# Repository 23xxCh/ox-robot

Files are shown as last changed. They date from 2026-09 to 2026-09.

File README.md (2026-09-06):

# 牛来 / ox-robot

有人靠近时它先停着等人喊；喊「牛来」先播电影「妈妈」片段，再礼貌听、想、说。人离开后，它才过自己的生活。

一块小智 S3 扩展板 V1.7 负责听、说、屏、灯、键、超声和四路舵机信号。笔记本上的 `brain/` 负责人格、记忆和动作编排。不把完整 ESP-Claw 固件并进小智。

- 仓库：https://github.com/23xxCh/ox-robot
- 最终汇报：[PDF](./outputs/submission-2026-09-06/牛来-最终汇报.pdf) · [Word](./outputs/submission-2026-09-06/牛来-最终汇报.docx)
- Checkpoint 1：[牛来机器人-进展说明-2026-09-05.md](./牛来机器人-进展说明-2026-09-05.md)
- Checkpoint 2：[牛来机器人-Checkpoint2-进展说明-2026-09-06.md](./牛来机器人-Checkpoint2-进展说明-2026-09-06.md)
- Submission：[牛来机器人-Submission-2026-09-06.md](./牛来机器人-Submission-2026-09-06.md)

## 架构

当前实现：**一块小智 ESP32-S3 板 + 笔记本本地大脑 + 按配置启用的云语音/模型服务**。

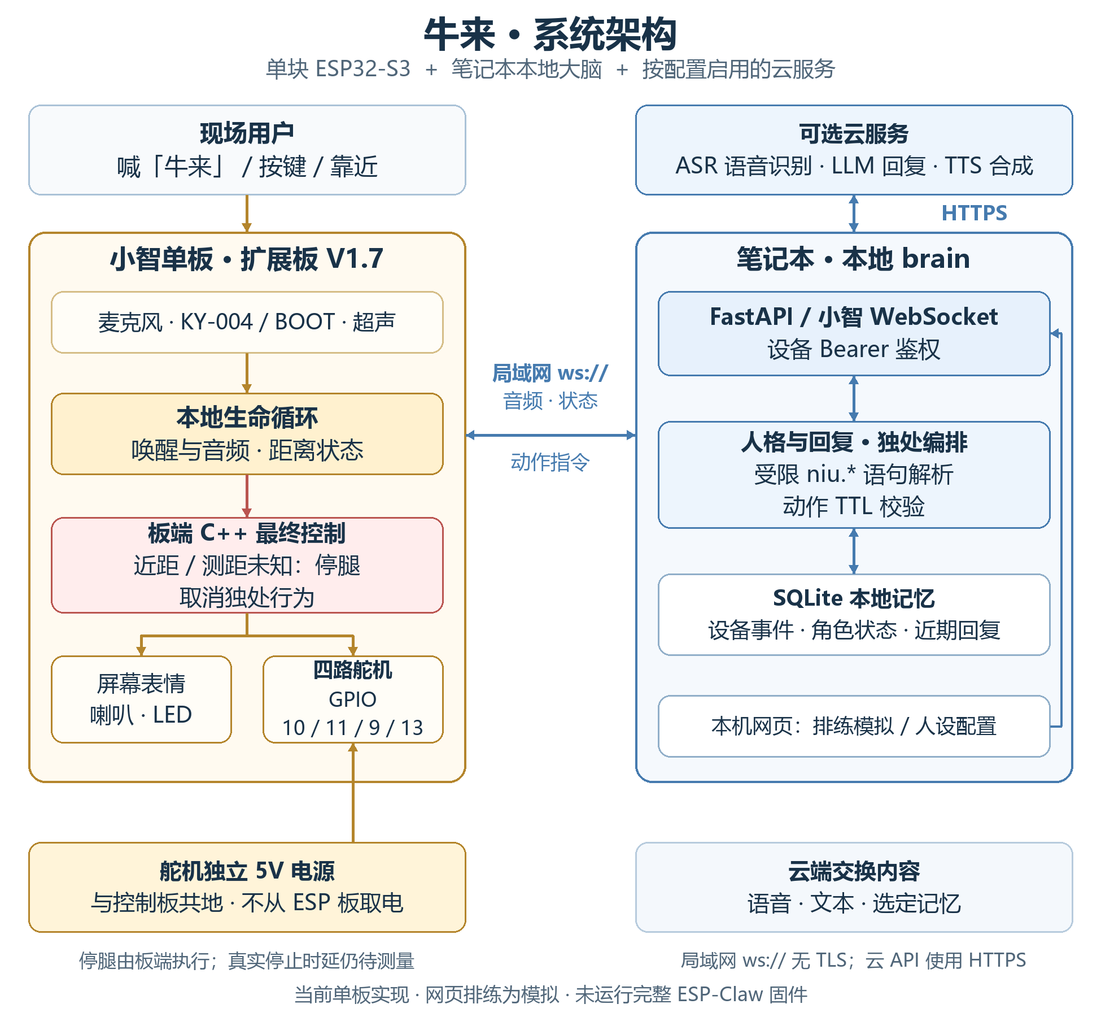
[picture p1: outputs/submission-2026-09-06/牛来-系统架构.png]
牛来当前系统架构


<details>
<summary>查看可编辑的 Mermaid 架构图</summary>

```mermaid
flowchart TB
    User["现场用户：喊牛来 / 按键 / 靠近"]

    subgraph Robot["牛来实体 · 小智 S3 扩展板 V1.7"]
        Input["麦克风 · KY-004 / BOOT · 超声测距"]
        Board["小智固件 + 牛来板型 overlay<br/>唤醒与音频 · 距离状态 · 本地生命循环"]
        Stop["板端 C++ 最终控制<br/>近距 / 测距未知：停腿并取消独处行为"]
        Face["屏幕表情 · 喇叭 · LED"]
        Servo["四路舵机<br/>GPIO 10 / 11 / 9 / 13"]
        Input --> Board
        Board --> Stop --> Servo
        Board --> Face
    end

    subgraph Laptop["笔记本 · brain"]
        Gateway["FastAPI / 小智 WebSocket<br/>设备 Bearer 鉴权"]
        Persona["人格与回复 · 独处编排<br/>受限 niu.* 语句解析 · 动作 TTL 校验"]
        Memory[("SQLite<br/>设备事件 · 角色状态 · 近期记忆")]
        Web["本机网页<br/>排练模拟 / 人设配置"]
        Gateway <--> Persona
        Persona <--> Memory
        Web --> Gateway
    end

    Cloud["可选云服务<br/>ASR 语音识别 · LLM 回复 · TTS 合成"]
    Power["舵机独立 5V 电源<br/>与控制板共地"]

    User --> Input
    Board <-->|"局域网 ws://：音频 / 状态 / 动作指令"| Gateway
    Gateway <-->|"HTTPS：音频 / 文本 / 选定记忆"| Cloud
    Power --> Servo

    classDef hardware fill:#fff3d6,stroke:#b7791f,color:#332500
    classDef software fill:#e9f3ff,stroke:#3675b5,color:#16324f
    classDef guard fill:#ffe8e8,stroke:#c44b4b,color:#5c2020
    class Input,Board,Face,Servo,Power hardware
    class Gateway,Persona,Memory,Web,Cloud software
    class Stop guard
```

</details>

- **物理控制在板端：** 连续有效远距约 8 秒才进入独处；近距或未知时优先停腿、取消独处吐槽，明确发起的礼貌会话另行处理。实际停止与静音时延仍待测。
- **语音需要按路径说明：** 本地「妈妈」片段在设备播放；完整问答依赖笔记本与配置的语音/模型服务。当前局域网使用 `ws://`，没有 TLS；网页排练结果是模拟。
- **实现边界：** 本轮未运行完整 ESP-Claw 固件；`niu.*` 是 Python 受限语句解析器，不是完整 Lua 运行时。舵机外供 5V，不从 ESP 板取电；继电器未使用。

## 仓库

| 路径 | 内容 |
|---|---|
| `brain/` | 本地大脑（FastAPI、测例、排练页） |
| `firmware/xiaozhi-niulai/` | 小智板型 overlay、`mama.ogg`、接线说明 |
| `firmware/niulai-*-test/` | 屏/喇叭、超声、四足 Arduino 测试 |
| `mechanical/` | 开框 / BOM 件 / 外壳接口 |
| `docs/` | 架构、PRD、SPEC |
| `outputs/牛来机器人-A2L打印包-v0.5/` | 打印包 |

## 接线

屏已经占用 **GPIO 21（SCL）** 和 **GPIO 47（MOSI）**。灯和键不能接这两脚，否则花屏。

| 功能 | GPIO | 说明 |
|---|---|---|
| 屏 ST7789 2" | 21 / 47 / 45 / 40 / 41 / 42 | SCL / MOSI / RST / DC / CS / BL |
| 喇叭 MAX98357 | 15 / 16 / 7 | BCLK / LRC / DIN |
| 麦 | 4 / 5 / 6 | WS / SCK / DIN |
| 超声 HC-SR04 | 8 / 17 | TRIG / ECHO |
| 舵机 SG90 ×4 | 10 / 11 / **9** / 13 | **5V 外供**；左后不要接 GPIO 12（充电指示） |
| KY-016 灯 S | **14** | 三针模块本轮只会红 |
| KY-004 键 S | **18** | 按下为低，开始礼貌听、想、说 |
| BOOT | 0 | 短按同样开始礼貌对话 |

KY-016：`-`=GND，中间=5V，`S`=14。  
KY-004：`-`=GND，中间 VCC 可空，`S`=18。  
舵机黄=信号、橙=外供 5V、棕=GND。一直转的那只，先确认黄线在 10 / 11 / 9 / 13，不要接到 12（充电指示）或 14 / 15 / 16 / 21。

## 固件

板型 `niulai-s3-expand-v17`，源码 overlay 在 `firmware/xiaozhi-niulai/`，构建在小智 `xiaozhi-esp32` 树里。

- 唤醒词：`niu lai`（单次「牛来」）
- 唤醒 / BOOT / KY-004：先 `PlaySound(OGG_MAMA)` 约 2.2 秒，再礼貌听、想、说，走私有大脑；立刻把四腿写回 1500 µs；不打开小智云
- 超声近距视为有人：腿立刻中位，打断 SECRET 吐槽，等人喊。礼貌对话里若让它动，可短促 `niu.walk`/`niu.turn`（ttl≤2000）；靠近仍冻腿
- SECRET：连笔记本私有 `ws://192.168.18.144:8000/xiaozhi/v1/`（2026-09-06 当前 WLAN），使用设备 Bearer 鉴权。LLM + `qwen3-tts-flash` Dylan，有冷却和安静间隔。拒绝 xiaozhi.me。断链时走已有本地片段回退，实际听感须真机验收。
- SECRET 步态：约 800 ms 随机步态，随后约 2 s 停在 1500 µs。360° 舵机不会一直转。喇叭音量 90

构建树：`E:\XIAOZHI_NATIVE\xiaozhi-esp32`。烧录前备份相关分区并确认接线与四腿悬空固定；服务故障本身不构成重刷固件的理由。靠近会请求 `ResetDecoder()`，实际静音时延待测。

```powershell
# ESP-IDF 6.0.2
Set-Location "E:\XIAOZHI_NATIVE\xiaozhi-esp32"
python scripts/build.py niulai-s3-expand-v17
idf.py -p COM6 flash
```

COM 口按设备管理器改。烧完先看黄牛脸，再按键或喊「牛来」。

## 本地大脑

```powershell
pip install -r brain/requirements.txt
python -m pytest
python -m brain.app
```

排练页：http://127.0.0.1:8000/  
人设页：http://127.0.0.1:8000/life （笔记本浏览器，不驱动真机冻结，也不连小智云）

设备连接必须提供 `Authorization: Bearer <NIULAI_DEVICE_TOKEN>`；三个 IM 入口必须提供独立的 `Authorization: Bearer <NIULAI_IM_TOKEN>`。在本机 `brain/.env` 或根 `.env` 配置，空值会拒绝连接；示例见 [.env.example](.env.example)。网页与 `/api/v1/*` 只对真实 localhost 开放。`python -m brain.app` 已禁用代理头；自行运行 uvicorn 时也要加 `--no-proxy-headers`。

微信 ClawBot（iLink，不是公众号）：`POST http://192.168.18.144:8000/im/clawbot/event`。
OpenClaw / 自建转发须附上上述 IM 入站 Bearer。出站另用本机环境变量 `NIULAI_CLAWBOT_TOKEN`（可选 `NIULAI_CLAWBOT_BASE_URL`），不能拿它充当入站鉴权。未配置出站 token 时只进测试发件箱，不假装已连上微信。人在场时微信只礼貌回、不走腿、不泄密。

无 `NIULAI_LLM_*` key 时测例仍应通过。90 秒路演只演板端，不演 /life 闲聊。

## 文档

| 文件 | 用途 |
|---|---|
| [牛来机器人-进展说明-2026-09-05.md](./牛来机器人-进展说明-2026-09-05.md) | Checkpoint 1 进展 |
| [牛来机器人-Checkpoint2-进展说明-2026-09-06.md](./牛来机器人-Checkpoint2-进展说明-2026-09-06.md) | Checkpoint 2 进展 |
| [牛来机器人-Submission-2026-09-06.md](./牛来机器人-Submission-2026-09-06.md) | 12:00 交卷稿 |
| [docs/architecture-niulai-local-brain-2026-09-05.md](./docs/architecture-niulai-local-brain-2026-09-05.md) | 当前软件架构 |
| [docs/prd-niulai-life-v2-2026-09-05.md](./docs/prd-niulai-life-v2-2026-09-05.md) | 生命感 PRD |
| [firmware/xiaozhi-niulai/README.md](./firmware/xiaozhi-niulai/README.md) | 板型与烧录 |

## 团队

陈熙贤（硬件）· 潘炜德（软件）· 微微（产品 & 商业）

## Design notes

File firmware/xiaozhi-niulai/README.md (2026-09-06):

# 牛来小智板型 `niulai-s3-expand-v17`

源码：`E:\XIAOZHI_NATIVE\xiaozhi-esp32\main\boards\niulai-s3-expand-v17\`
overlay 同步在本目录。同步生命循环时须同时复制 `niulai_life.cc`、`niulai_life.h` 和 `niulai_presence.h`。不要合完整 ESP-Claw。

基于官方 `bread-compact-wifi-lcd`。继电器不用。舵机 5V 必须外供，不要从 ESP 5V 取电。

## 必须改线（屏会抢 21/47）

扩展板 2 寸屏已经占用：

| 屏脚 | GPIO |
|---|---|
| SCL | **21** |
| MOSI/SDA | **47** |
| RST | 45 |
| DC | 40 |
| CS | 41 |
| BL | 42 |

所以：

- **KY-016 的 S 不要接 21，改接到 GPIO 14**
- **KY-004 的 S 不要接 47，改接到 GPIO 18**
- 灯不要占 GPIO 12（充电指示 CHRG）。左后舵机改接 **GPIO 9**

KY-016 三针模块只有一路 PWM，所以现在只会红。要红绿蓝混色需要再引出 G/B 两路。

## 当前固件接线

| 功能 | GPIO | 说明 |
|---|---|---|
| KY-016 S（红） | **14** | PWM，共阴极，高电平更亮 |
| KY-004 S | **18** | 上拉，按下为低；点一下开始礼貌听、想、说 |
| 喇叭 MAX98357 | BCLK 15 / LRC 16 / DIN 7 | |
| 屏 ST7789 | SCL 21 MOSI 47 RST 45 DC 40 CS 41 BL 42 | invert on |
| 麦 I2S | WS 4 / SCK 5 / DIN 6 | 板载 |
| 超声 | TRIG 8 / ECHO 17 | 近距 PRESENT 立刻冻腿；约 8 秒无近距才 SECRET 对角晃。ECHO 建议 1k+2k 分压到 3.3V |
| 舵机 | 10 / 11 / **9** / 13 | 外供 5V。左后不要接 12：板上 12 是充电指示 CHRG |
| BOOT | 0 | 短按切换聆听；启动时进入配网 |

KY-016：`-`=GND，中间=5V，`S`=GPIO14。
KY-004：`-`=GND，中间 VCC 可空，`S`=GPIO18。

屏上是黄牛来脸。人靠近：腿停，打断吐槽，切断私有 WSS，等人喊；脸只用听/笑。人离开约 8 秒：随机小晃 + 吐槽脸；本轮候选固件的私有地址为 `ws://192.168.18.144:8000/xiaozhi/v1/`（冷却、可安静、最近 5 句不重复）。电脑服务目前仅绑定本机，尚未进行板端连接验收。断链播本地 `secret1/2/3.ogg`，不假装云端在聊。拒绝 xiaozhi.me。音量 90。

生命循环在 `niulai_life.cc`：200 ms 一轮，近距路径输出 1500 µs 冻腿，实际停止时延待测。礼貌对话里若让它动，可短促 `niu.walk`/`niu.turn`（ttl≤2000）；靠近仍冻。超时 ≠ 确认无人。SECRET 随机步态短促再停，避免 360° 舵机空转。靠近不播 `mama.ogg`。唤醒 / BOOT / 键：先停腿，播电影「妈妈」；至少 2.2 秒且音频排空后进入礼貌听、想、说。

## 唤醒与礼貌对话

- 唤醒词：`niu lai`（单次「牛来」）
- 唤醒后先播 `mama.ogg`（电影「妈妈」），再走私有大脑礼貌听、想、说，**不打开小智官网**
- BOOT / 开始聆听同样：妈妈片段 → 礼貌对话，禁止连官方 websocket
- 启动时跳过官方 OTA，避免被官网固件覆盖
- KY-004 短按同样开始礼貌对话

## 编译烧录

需要 ESP-IDF 6.0.2（本机 `E:\AI_TOY_TOOLS\esp-idf-v6.0.2`）：

```powershell
$env:Path = "C:\Program Files\Git\cmd;" + $env:Path
$env:IDF_PATH = "E:\AI_TOY_TOOLS\esp-idf-v6.0.2"
$env:IDF_TOOLS_PATH = "E:\AI_TOY_TOOLS\espressif"
$env:PYTHONUTF8 = "1"
$env:PYTHONIOENCODING = "utf-8"
. "$env:IDF_PATH\export.ps1"
Set-Location "E:\XIAOZHI_NATIVE\xiaozhi-esp32"
python scripts/build.py niulai-s3-expand-v17
```

COM 口按设备管理器改。先确认喇叭、超声、独立舵机供电接线和四腿悬空固定，再单独执行烧录命令。当前构建未烧录。服务故障本身不构成重刷固件的理由；WLAN 地址变化时须同步固件地址并验证服务可达。靠近会请求 `ResetDecoder()`，实际静音时延待测。烧完先看黄牛脸，再按 KY-004 或喊「牛来」。左后黄线必须在 GPIO 9，不要接 12。

实体准备完成后的烧录命令（沿用上方 IDF 环境）：

```powershell
idf.py -p COM6 flash monitor
```

## 小智主干挂钩（不在本 overlay 目录里）

本轮妈妈定时与回复过滤增量保存在 [application-intro-2026-09-06.patch](application-intro-2026-09-06.patch)，前后源码哈希见 [本轮记录](../../.grok-loop/evidence/runs/20260906-codex-round2.json)。仅适用于 `.scratch/codex-round2/native-before/` 对应的已修改小智基线，不能当成完整上游补丁。应用前先核对基线并运行 `git apply --check`，不要对已经包含该改动的构建树重复应用。

在上述 intro 补丁之后应用 [application-dialogue-2026-09-06.patch](application-dialogue-2026-09-06.patch)。它只修改 `main/application.cc`，加入可选本机设备凭据、启动前加载模型，以及传感器抖动时保留显式礼貌会话；不是完整上游补丁。应用前 SHA256：`458AE720797A69152B115FB09D0DBFC7CA3932911FAF7C070C74763197CC37A2`；应用后：`20B99D565A9E04A5207163A648FBAD95B51CF0C98990BD41793EC9C69A303EF9`。已在隔离目录通过 `git apply --check`、实际回放和结果哈希核对。

本机私有 `main/niulai_device_private.h` 可提供 `NIULAI_DEVICE_TOKEN`；缺头文件时保留 NVS token。补丁不包含凭据值，私有头文件不随 overlay 发布。

牛来的模型与资产随匹配固件发布，更新模型时须同时更新匹配的 `assets` 分区。启动在音频任务运行前加载一次，随后跳过联网资产下载与再次加载；本轮不支持运行中热换模型，避免引擎引用已解除映射的模型。缺资产或加载失败会记错误日志，需修复本地资产后重启。近距或 UNKNOWN 始终停腿并取消 SECRET；明确唤醒、BOOT 或 KY-004 发起的礼貌会话会保留，显式取消与断线仍会终止它。

本地可运行检查（使用实际源码；不会连接板子）：

```powershell
python firmware/xiaozhi-niulai/check_application_intro.py --source E:/XIAOZHI_NATIVE/xiaozhi-esp32/main --compiler E:/AI_TOY_TOOLS/espressif/tools/xtensa-esp-elf/esp-15.2.0_20251204/xtensa-esp-elf/bin/xtensa-esp32s3-elf-g++.exe
```

启动与传感器回归检查支持同样的 `--source`、`--compiler` 参数。替换为实际 native `main` 目录和支持 C++17 的 GCC 兼容编译器路径：

```powershell
python firmware/xiaozhi-niulai/check_application_voice_startup.py --source path/to/xiaozhi-esp32/main --compiler path/to/xtensa-esp32s3-elf-g++.exe
```

该检查提取实际源码，以 C++ 常量求值验证停腿、礼貌保留、SECRET 取消、启动状态保护及模型加载顺序；不生成固件、不接触私有头文件，不代替真机音频验收。

2026-09-06 接管修复：测距超时、非数值或超出 2–400 cm 时进入 UNKNOWN、清除远距计时并停腿；只有连续有效远距达到 8 秒才进入 ABSENT。已排队的 SECRET 请求执行前再次核对状态。音频取消仍经过应用任务调度，停止时延须真机测量；源码或构建通过不代表时延达标。

这些改动在构建树 `E:\XIAOZHI_NATIVE\xiaozhi-esp32`，板型为 `niulai-s3-expand-v17` 时才生效：

- `main/application.cc`：`IsNiulaiBoard()`。启动跳过官方 OTA/激活；拒绝打开官方 websocket 音频通道；唤醒 / BOOT / KY-004 走 `NiulaiStartPoliteChat()`（妈妈片段、定时事件与播放排空后再听）；近距走 `NiulaiEnterPresent()` 冻腿打断吐槽。
- `main/boards/common/board.h`：`virtual void ParkActuators() {}`，牛来板 override 成四腿 1500 µs。
- `main/assets/lang_config.h`：`OGG_MAMA` / `OGG_HI` / `OGG_SECRET1..3` 指向本地 Opus 剪辑。

不要打开 xiaozhi.me 点升级。

## Overlay vs native：本地 secret 剪辑

Overlay `AskBrainSecret()` **只** `Schedule(NiulaiEnterSecret)`，本目录没有 `PlaySound`、没有 clip 轮播。断链本地闷声在 native `main/application.cc` `NiulaiEnterSecret()`：WSS 打开失败才 `PlaySound(OGG_SECRET1/2/3)` 轮转；每 3 拍可安静。靠近路径走 `NiulaiEnterPresent()`，**不**播 `OGG_MAMA`。

| Overlay 资源 | Native 符号 / 路径 |
|---|---|
| `firmware/xiaozhi-niulai/secret1.ogg` | `Lang::Sounds::OGG_SECRET1` ← `main/assets/common/secret1.ogg` |
| `firmware/xiaozhi-niulai/secret2.ogg` | `Lang::Sounds::OGG_SECRET2` ← `main/assets/common/secret2.ogg` |
| `firmware/xiaozhi-niulai/secret3.ogg` | `Lang::Sounds::OGG_SECRET3` ← `main/assets/common/secret3.ogg` |
| `firmware/xiaozhi-niulai/mama.ogg` | `Lang::Sounds::OGG_MAMA` ← `main/assets/common/mama.ogg`（仅唤醒 / BOOT / KY-004） |
| `firmware/xiaozhi-niulai/hi.ogg` | `Lang::Sounds::OGG_HI` ← `main/assets/common/hi.ogg` |

资源存在 ≠ 已进当前 native 板型编译 ≠ 喇叭听过。三列证据见 [fallback-evidence.md](fallback-evidence.md)。本切片不复制 native 文件、不烧板、不声称 heard-on-device。

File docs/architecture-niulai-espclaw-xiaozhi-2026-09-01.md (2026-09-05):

# 「牛来」ESP-Claw + AI 小智双节点系统架构

**文档版本：** 2.0 Proposal  
**日期：** 2026-09-01  
**适用范围：** AIX ORIGIN 硬件黑客松 P0 原型  
**状态：** 推荐方案；需通过双板与电源物料门禁后冻结  
**覆盖关系：** 本文针对“必须真实使用 ESP-Claw 与 AI 小智”的新要求，覆盖 `architecture-niulai-robot-2026-08-31.md` 中的单板运行时选择；原文的安全、机械、电源和测试要求继续有效。

## 1. 结论

黑客松版本采用：

> **两块 ESP32-S3、两个独立固件、一个人格状态源、一条本地语义链路、一个独立硬件安全边界。**

- **AI 小智语音节点**负责听、说、实时语音会话和公开对话。
- **ESP-Claw 生命控制节点**负责人格状态、秘密活动、记忆、动作编排、传感器和身体控制。
- **ESP-Claw 控制节点是人格与身体的唯一权威。** 小智只有语音会话状态，不得自行改变人格或直接控制执行器。
- 两板通过短线 3.3 V UART 交换有版本、序号、TTL、`persona_epoch` 和 CRC 的语义事件；不通过板间链路传输原始音频、PWM、轮速或舵机角度。
- 人员检测、避障、低电、动作租约、急停和最终执行器裁决全部留在 ESP-Claw 控制板和硬件侧，绝不依赖 UART、Wi-Fi、云端或 LLM。
- 另设一根由控制板直接控制的小智功放 `AMP_MUTE/EN` 硬件线；发现人、状态未知或急停时可立即静音，不等待语音软件响应。

不采用：把 ESP-Claw 与 xiaozhi-esp32 两套完整固件硬合并到同一颗 ESP32-S3。

## 2. 架构驱动

### 2.1 功能驱动

1. 无人时，牛来秘密活动、观察、吐槽并留下轻量记忆。
2. 发现人或无法确认人员状态时，立即装死并清除私密动作与语音。
3. 听到“牛来”后，从装死状态公开复活，先回答本地“妈妈”，再允许公开语音互动。
4. ESP-Claw 必须真实参与 Event、Memory、Capability/Lua 和行为编排。
5. AI 小智必须真实参与本地唤醒/音频链路和至少一次 ASR→LLM→TTS 公开对话。
6. 核心三分钟故事在断网时仍可完成；云端只增加内容丰富度。

### 2.2 非功能驱动

| ID | 要求 | 架构响应 |
|---|---|---|
| NFR-SAFE-001 | 非安全模块不得直写执行器 | 控制板 C/C++ Safety Supervisor 与私有 HAL 拥有最终权限 |
| NFR-RT-001 | `PRESENT/UNKNOWN` 到运动撤销不超过 300 ms | 人员传感、安全裁决和电机停止均在控制板本地短路径 |
| NFR-OFFLINE-001 | 断网仍完成核心故事 | 本地 KWS/按钮、本地“妈妈”、本地台词和本地动作 |
| NFR-REL-001 | 重启、断链、超时默认安全 | 握手前 `BOOT_SAFE`；动作租约；链路看门狗；STBY 下拉 |
| NFR-DEMO-001 | 三分钟 Demo 连续 10 次通过 | 冻结版本、离线兜底、场景回放和双板故障注入 |
| NFR-AUDIO-001 | 电机/扬声器不破坏语音 | 语音与执行器分板、分电源域、星形接地、P0 半双工优先 |
| NFR-DEV-001 | 三人短周期可并行 | 语音、生命控制、机械电源三条工作流由 UART 契约解耦 |

## 3. 方案比较

| 方案 | 是否真实使用两套系统 | 黑客松风险 | 判断 |
|---|---:|---:|---|
| 一颗 S3 合并两套完整固件 | 是 | 极高 | 拒绝；IDF、入口、分区、NVS、网络、音频任务和内存模型冲突 |
| 两块 S3，UART 语义互联 | 是 | 最低 | **P0 推荐**；边界清楚，可独立刷写与故障定位 |
| 小智为主，只移植 ESP-Claw 思想/组件 | 部分 | 中 | 未来单板产品路线；不能宣称 P0 运行完整 ESP-Claw |
| ESP-Claw 单板 + PC 模拟小智语音网关 | 部分 | 中 | 双板缺货时救场；玩具依赖 PC，演示独立性较弱 |

### 3.1 架构模式（Architecture Pattern）

本方案是一个**双节点、事件驱动、分层的嵌入式系统**：每块板内部保持模块化单体，板间只通过有类型的语义事件协作。它不是微服务架构，也不是两个 Agent 对等争抢控制权。

- **语音平面：** 小智节点处理实时音频和公开对话。
- **生命平面：** ESP-Claw 节点处理人格、记忆、环境事件和行为编排。
- **安全平面：** 控制板上的固定规则与硬件链路覆盖前两者，拥有最终否决权。
- **集成模式：** UART 消息合同 + 单一人格权威 + 有时限的动作/语音租约。

### 3.2 关键取舍（Trade-off Analysis）

- 用一块额外 S3、少量 BOM 和协议开发成本，换取两套上游工程可独立升级、可并行开发、可隔离故障。
- 接受 P0 体积和功耗略高，换取 Demo 阶段的可调试性；产品化后再以测量结果决定是否裁剪成单板。
- UART 不传原始音频和执行器细节，牺牲少量跨板灵活性，换取带宽确定性、权限边界和本地安全闭环。
- P0 不追求多设备横向扩展（Scalability）；只在协议中保留设备身份和版本字段，避免为尚不存在的规模提前复杂化。

## 4. 总体架构

```text
                         可选互联网 / 本地服务器
                ┌────────────────────────────────┐
                │ 小智 Server                    │
                │ ASR / 对话 LLM / TTS / MCP     │
                └───────────────┬────────────────┘
                                │ WebSocket 或 MQTT+UDP
                                ▼
┌──────────────── AI 小智语音节点 ESP32-S3 A ────────────────┐
│ Mic → Audio Codec → ESP-SR AFE → Opus → 实时语音协议       │
│        本地唤醒 / AEC / VAD          ↕                     │
│ Speaker ← Audio Output ← Opus Decode                       │
│ Voice FSM: IDLE / LISTENING / THINKING / SPEAKING / FAILED │
│ 设备 MCP：仅暴露 niu.get_state / niu.perform 等窄工具       │
└──────────────────────┬──────────────────────────────────────┘
                       │ 3.3V UART 语义协议
                       │ + AMP_MUTE/EN 硬线
                       ▼
┌──────────────── ESP-Claw 生命控制节点 ESP32-S3 B ──────────┐
│ ESP-Claw: Event Router / Memory / Skills / Capability / Lua │
│                         │ 语义 ActionIntent                 │
│                         ▼                                   │
│ Persona FSM → Action Gateway → Safety Supervisor            │
│      ▲                                  │                   │
│ Presence / Wake / Memory                 ▼                   │
│                              Motion / Servo / OLED / Audio   │
│ Presence雷达 / HC-SR04 / Battery / E-stop / Watchdog         │
└──────────────────────┬──────────────────────────────────────┘
                       │
                       ▼
           两驱电机 / 头部两轴 / 嘴巴 / 双眼 OLED

实体急停：直接切断电机与舵机执行器电源，并硬件拉低 AMP_MUTE；
控制板逻辑保持上电，用于锁存故障与记录原因。
```

### 4.1 部署与启动边界（Deployment）

- 两块板分别编译、烧录、回滚；禁止把两套完整固件在 P0 合成同一个工程。
- 上电时控制板先进入 `BOOT_SAFE`，小智板先保持扬声器静音；完成版本握手和本地自检后才允许进入人格状态。
- 小智 Server 可部署在局域网电脑或云端，但它下线不能破坏装死、复活、本地“妈妈”和运动安全。
- 发布包必须绑定小智固件版本、ESP-Claw 固件版本、板间协议版本和角色资源版本，禁止只更新一侧后直接上场。

## 5. 单一权威与双平面

### 5.1 唯一状态所有者

| 状态/资源 | 唯一权威 | 说明 |
|---|---|---|
| `persona_state`、`persona_epoch` | ESP-Claw 控制板 | 小智只能读取，不能修改 |
| 人员三态、安全状态、动作租约 | ESP-Claw 控制板 | 不跨板裁决 |
| 语音会话状态 | 小智语音板 | 控制板读取并可取消/静音 |
| 公开对话内容 | 小智 Server/LLM | 必须受控制板下发的语音策略约束 |
| 秘密行为和轻量人格记忆 | ESP-Claw 控制板 | 决定何时秘密活动、记住什么 |
| 执行器 | Safety Supervisor | 任何 Agent、Lua、MCP 只能提交意图 |

### 5.2 双平面

1. **确定性控制平面**：人员检测、装死、急停、避障、低电、动作租约、电机与舵机控制。运行在控制板 C/C++，优先级最高。
2. **创意智能体平面**：ESP-Claw 记忆、秘密行为组合、小智公开对话、云端 LLM。只产生短文本、情绪标签和白名单动作意图。

### 5.3 语音所有权租约

同一时刻只允许一个内容源说话：

| 人格状态 | 允许说话的源 | 规则 |
|---|---|---|
| `FREEZE_DETECTED` | 无 | 硬件静音；等待“牛来” |
| `PUBLIC_ALIVE` | 小智 | 公开对话；ESP-Claw 私密 Agent 暂停 |
| `SECRET_ALIVE` | ESP-Claw 或本地台词库 | 小智对话 Agent 静默，仅充当受控 TTS/播放端 |
| 任一安全停止态 | 无 | 清队列、撤销动作、硬件静音 |

控制板发出的每个语音许可都绑定 `persona_epoch` 和截止时间。状态变化后，旧 ASR、LLM、TTS 或音频结果全部丢弃。

## 6. 状态模型

不要把安全状态和人格状态混成一个枚举；采用两个正交状态机。

### 6.1 Safety FSM

```text
BOOT_SAFE ──自检通过──► NORMAL
    ▲                    │
    │ 关键状态未知/故障   ├──► SAFE_STOP
    │                    │
    └────重新握手/自检────┘

任意状态 ──实体急停──► E_STOP_LATCHED
E_STOP_LATCHED ──实体释放 + 本地重新武装──► BOOT_SAFE
```

### 6.2 Persona FSM

```text
上电默认
   ▼
FREEZE_DETECTED  ◄──────────── PRESENT / UNKNOWN
   │
   │ 连续 ABSENT 达去抖时间（建议初值 5 秒）
   ▼
SECRET_ALIVE ──发现人/状态未知──► FREEZE_DETECTED
   ▲                                  │
   │ ABSENT + 公开会话结束             │ WAKE_NIULAI
   └──────────── PUBLIC_ALIVE ◄────────┘
                         │
                         └─会话超时且仍 PRESENT → FREEZE_DETECTED
```

`MAMA_RESPONSE` 是 `PUBLIC_ALIVE` 的进入动作，不再是说完一句就退回机械人格的独立终态。

### 6.3 状态优先级

```text
实体急停
  > 硬件/供电故障
  > PRESENT 或 UNKNOWN 导致装死
  > 障碍与低电
  > 用户“牛来”公开唤醒
  > 公开对话配套动作
  > 秘密自主活动
  > LLM 建议
```

## 7. 组件设计

### 7.1 AI 小智语音节点

| 组件 | 职责 | 禁止事项 |
|---|---|---|
| `audio_service` | I²S 采集/播放、Opus 队列、音量与功放状态 | 不控制身体执行器 |
| `afe_engine` | 本地唤醒、AEC、VAD | 不判断人格 |
| `voice_fsm` | 管理监听、思考、播放、打断和故障 | 不自行从装死切到公开人格 |
| `xiaozhi_protocol` | WebSocket 或 MQTT+UDP 语音通信 | P0 只启用一种主协议 |
| `niu_uart_bridge` | 将唤醒、语音状态和 MCP 意图转换为板间消息 | 不传原始音频和底层控制值 |
| `local_audio_assets` | 离线“妈妈”和故障提示 | 仅使用审核过的 asset_id |

### 7.2 ESP-Claw 生命控制节点

| 组件 | 职责 | 禁止事项 |
|---|---|---|
| `presence_adapter` | 输出 `PRESENT/ABSENT/UNKNOWN` 和 freshness | 不把超声波当人员传感器 |
| `safety_supervisor` | 急停、人员、障碍、低电、链路和看门狗仲裁 | 不访问网络、LLM 或文件系统 |
| `persona_fsm` | 唯一人格状态与 `persona_epoch` | 不直接写 GPIO |
| `life_engine` | 情绪、能量、秘密活动和行为选择 | 不越过安全优先级 |
| `action_gateway` | 验证动作名、来源、epoch、TTL 和参数枚举 | 不接受 PWM、裸角度或无限时长 |
| `motion_controller` | 有限速度、有限时长、动作租约与停止 | 链路断开后不延续旧动作 |
| `servo/display_controller` | 命名姿态和预设表情 | 不越机械限位 |
| `espclaw_bridge` | Event、Memory、Capability、Lua 接入 | Agent/Lua 不拥有最终执行权 |
| `niu_uart_link` | 板间握手、心跳、幂等、ACK 和故障统计 | 不能把链路故障解释成 ABSENT |

### 7.3 ESP-Claw 的最小真实使用证明

P0 至少满足：

1. `WAKE_DETECTED`、`PRESENT`、`ABSENT` 等进入 ESP-Claw Event Router。
2. Memory 保存至少一个会改变后续表现的字段，例如 `forced_mama_count`。
3. 一个 Skill/Lua 编排至少三种秘密行为，例如环顾、眨眼、低声吐槽。
4. 一个 Capability 通过 Action Gateway 请求命名动作。
5. Agent 超时或崩溃不会影响装死、停车和本地“妈妈”。

## 8. 板间接口

### 8.1 物理层

- 3.3 V TTL UART，全双工，短线，共地。
- 建议 460800 baud，8N1；线束较长或噪声严重时降速并复测。
- P0 不用 Wi-Fi/MQTT 作为板间安全链路。
- 增加独立 `AMP_MUTE/EN` 线，默认下拉为静音。

### 8.2 帧格式

采用 `COBS + 固定头 + 紧凑 JSON Payload + CRC32`，最大帧 512 B。

```text
protocol_version
sender_boot_id
message_type
seq
correlation_id
persona_epoch
ttl_ms
payload_length
payload
crc32
```

规则：

- 接收端使用自己的单调时钟判断 TTL，不依赖网络时间。
- `boot_id + seq` 识别重启、重复和乱序。
- 一次性动作使用 `correlation_id` 幂等；重发不得重复执行。
- 未知版本、CRC 错误、超长帧和未知动作全部拒绝并计数。
- 队列有界；拥塞先丢遥测，不能丢 `CANCEL_AUDIO`、状态和故障消息。
- 链路只传语义事件；不传 PCM、Opus、任意 URL、PWM、轮速和裸舵机角度。

### 8.3 消息合同

#### 小智 → 控制板

| 类型 | 关键字段 | 用途 |
|---|---|---|
| `HELLO` | version、firmware、capabilities、boot_id | 握手与能力协商 |
| `HEARTBEAT` | voice_state、heap、faults | 链路健康 |
| `WAKE_DETECTED` | source、confidence、session_id | 统一映射为 `WAKE_NIULAI` |
| `VOICE_STATE` | IDLE/LISTENING/THINKING/SPEAKING/FAILED | 同步会话状态 |
| `ACTION_REQUEST` | action、enum_params、ttl、epoch、action_id | 小智 MCP 高层动作请求 |
| `PLAYBACK_EVENT` | started/ended/cancelled/failed、session_id | 嘴部/表情有限联动 |
| `AUDIO_FAULT` | reason | 声学链路降级 |
| `CLOUD_FAULT` | reason | 退回本地交互 |

#### 控制板 → 小智

| 类型 | 关键字段 | 用途 |
|---|---|---|
| `HELLO_ACK` | accepted_version、boot_id | 建立会话 |
| `AUTHORITATIVE_STATE` | safety、presence、persona、epoch | 唯一权威状态 |
| `VOICE_POLICY` | listen、cloud、mute、max_volume、epoch | 控制是否能听/说 |
| `PLAY_LOCAL_ASSET` | asset_id、epoch、deadline | 离线“妈妈”等固定音频 |
| `SPEAK_REQUEST` | filtered_text、epoch、deadline | P1 秘密台词 TTS |
| `CANCEL_AUDIO` | epoch、reason | 清除迟到或私密音频 |
| `ACTION_RESULT` | action_id、accepted/rejected/done/cancelled、reason | 动作反馈 |
| `LINK_POLICY` | normal/degraded | 降级策略 |

### 8.4 超时与失败安全

| 项目 | 建议初值 | 失败行为 |
|---|---:|---|
| 心跳周期 | 200 ms | 仅健康同步 |
| 心跳可疑 | 400 ms | 禁止新的跨板动作 |
| 链路失效 | 600 ms | 取消小智来源动作并停车；不自动恢复旧动作 |
| 普通 ACK | 100 ms | 只重试一次，随后降级 |
| `WAKE_DETECTED` 新鲜度 | 500 ms | 过期丢弃 |
| `CANCEL_AUDIO` | 50 ms | 未确认时保持硬件 MUTE |
| 运动续租 | 50 ms | 连续 100 ms 未续租即停车 |
| 动态语音总截止 | 5 s | 丢弃并使用本地资源 |

链路恢复稳定 2 秒后才允许重新启用跨板功能，且不得恢复断线前的动作或语音。

## 9. 关键数据流

### 9.1 被发现后装死

```text
毫米波 PRESENT/UNKNOWN
  → Safety Supervisor（本地）
  → 撤销动作租约 + 电机停车 + 舵机回安全姿态
  → Persona = FREEZE_DETECTED，epoch++
  → AMP_MUTE 硬件拉低
  → UART CANCEL_AUDIO（异步确认）
  → 清除私密台词、表情和动作队列
```

该路径不经过 ESP-Claw Agent、小智、UART、Wi-Fi 或 LLM 才能完成停车。

### 9.2 “牛来”公开复活

```text
小智本地 KWS 检测“牛来”
  → WAKE_DETECTED(session_id)
  → 控制板设置 PRESENT hold，Persona = PUBLIC_ALIVE，epoch++
  → 眼睛/头/嘴进入公开复活动作
  → PLAY_LOCAL_ASSET("mama")
  → 小智播放本地“妈妈”
  → 允许公开语音会话
```

隐藏按钮产生同一个 `WAKE_NIULAI` 事件作为演示兜底，但真实语音验收必须单独记录。

### 9.3 公开对话与动作

```text
Mic → 小智 AFE/Opus → ASR/LLM/TTS → Speaker
                         │
                         └─ MCP niu.perform("happy_nod")
                              → UART ACTION_REQUEST
                              → Action Gateway
                              → Safety Supervisor
                              → 命名姿态
```

MCP 工具只等待“已接受/已拒绝”，不阻塞到动作完全结束。

### 9.4 无人秘密活动

```text
连续 ABSENT 达去抖时间
  → Persona = SECRET_ALIVE，epoch++
  → 小智公开对话 Agent 静默
  → ESP-Claw Event/Memory/Skill 选择秘密行为
  → ActionIntent → Action Gateway → Safety Supervisor
  → 短动作 + 本地台词/受控 TTS
```

任何 `PRESENT/UNKNOWN` 都抢占以上流程。

## 10. 数据模型

| 实体 | 关键字段 | 所有者/存储 |
|---|---|---|
| `AuthoritativeState` | safety、presence、persona、epoch、entered_ms | 控制板 RAM |
| `VoiceSession` | session_id、state、started_ms、last_update_ms | 小智板 RAM |
| `BehaviorMemory` | forced_mama_count、curiosity、energy、recent_behavior_ids | ESP-Claw Memory/FATFS；P0 可会话级 |
| `ActionIntent` | source、action、params、epoch、ttl、action_id | 控制板有界队列 |
| `ActionLease` | action_id、allowed_action、expires_ms、cancel_reason | 控制板 RAM |
| `LinkPeer` | boot_id、last_seq、last_heartbeat、capabilities、error_counts | 两板 RAM |
| `AudioAsset` | asset_id、hash、duration、content_class | 小智板只读 Flash/assets |
| `EventLog` | seq、monotonic_ms、source、type、state、reason、correlation_id | 两板串口 JSONL + RAM ring |

P0 不持久化原始麦克风音频、照片或长期身份数据。

## 11. 安全、隐私与权限

### 11.1 永远留在控制板/硬件的能力

- 实体急停与重新武装。
- 人员三态融合与 freshness。
- 障碍、低电、过流/温升和 Brownout 处置。
- 电机 PWM、STBY/EN、舵机 PWM 与机械限位。
- 动作租约、限速、限时、停止距离和最终人格状态。
- 是否允许说话、移动或重新开始公开会话的最终决定。

### 11.2 LLM 允许与禁止

LLM 只允许：

- 生成短台词和情绪标签。
- 提议枚举的高层动作。
- 读取有限、脱敏、非安全关键的上下文。

LLM 禁止：

- 输出 PWM、轮速、舵机角度或无限时长动作。
- 修改安全阈值、判断人员存在或解除急停。
- 创建任意 URL、下载 Lua 或恢复过期动作。
- 让旧 epoch 的迟到结果重新发声或运动。

### 11.3 密钥与数据

- Provider 密钥保存在小智 Server/本地网关，不进入固件仓库和串口日志。
- 控制板不开放未鉴权的局域网控制面；P0 优先只保留 UART 与 USB 调试。
- 原始语音是否上传需在现场明确提示；P0 不落盘原始语音。

## 12. 电源与物理设计

```text
2S 带保护电池
  ├─ 逻辑稳压 ── ESP-Claw 控制板 + 传感器 + OLED
  ├─ 语音/功放稳压 ── 小智板 + Codec + Amp + Speaker
  ├─ 急停链路 ── 电机稳压 ── H桥 ── 两驱电机
  └─ 急停链路 ── 舵机稳压 ── 头部/嘴部舵机
```

- 所有电源域星形共地；电机和舵机回流不得穿过麦克风/Codec 地路径。
- 小智板、麦克风和 Codec 远离 H 桥、电机线和降压电感。
- `AMP_MUTE/EN` 默认静音；由控制板与急停硬件共同约束。
- P0 语音窗口优先暂停轮子和非必要舵机；全双工 AEC 作为增强，不设为核心门禁。

## 13. NFR 验证矩阵

| NFR | 验证方法 | 通过标准 |
|---|---|---|
| 人员抢占 | `SECRET_ALIVE` 移动中注入 PRESENT/UNKNOWN | 控制命令撤销 ≤300 ms；不继续私密语音 |
| 板间断链 | 运行中拔 UART TX/RX、重启任一板 | 停车、静音、不恢复旧动作 |
| 重复/乱序 | 重放同一 action_id、乱序 seq、旧 epoch | 不重复执行；全部拒绝并记录 |
| 急停 | 移动、舵机和播音中按下 | 执行器断能、功放静音、只能本地重新武装 |
| 离线 | 关闭外网和小智 Server | 完成秘密活动、装死、按钮/本地唤醒、本地“妈妈”和安全闭环 |
| 语音 | 约定距离/噪声下说“牛来”20次 | 至少18次 `source=voice` 命中；按钮结果分开统计 |
| MCP越权 | 请求原始 PWM、越界参数、旧 epoch | 100% 拒绝且无执行器输出 |
| 声学/电源 | 最大音量、电机启停、舵机组合 | 无 Brownout；KWS/录音达到约定指标 |
| Demo | 冻结版本连续演出 | 10次三分钟无死机、撞击、倾倒或人格穿帮 |

## 14. 技术栈与版本策略

| 节点 | 技术 | 决策 |
|---|---|---|
| 小智语音板 | `78/xiaozhi-esp32` | 选择有 AEC 音频硬件支持的已验证板型；固定 tag/SHA 与对应 ESP-IDF |
| 生命控制板 | `espressif/esp-claw` `application/edge_agent` | 从 `eda_robot_pro` 派生 `niu_robot`；固定 tag/SHA 与其已验证 ESP-IDF |
| 控制与安全 | C/C++ + FreeRTOS | 最高优先级、固定内存、有界队列 |
| 创意行为 | ESP-Claw Event/Memory/Capability/Lua | 仅高层语义和低频异步行为 |
| 板间协议 | UART + COBS + JSON + CRC32 | 简单可抓包，支持版本/幂等/TTL |
| 云端语音 | 小智 Server | P0 只选一套 Server 与一种主传输协议 |
| 机械 | FreeCAD 参数化骨架 + 生成式外壳 | 外观不承担承力与孔位基准 |

两块板允许分别冻结各自已验证的 ESP-IDF，不要求为了“统一版本”强行升级或回退。

## 15. 团队分工

| 工作流 | 负责人 | 首要产出 |
|---|---|---|
| 小智语音节点 | 计算机成员 A | 独立唤醒/对话/TTS、UART Bridge、一个 MCP 工具 |
| ESP-Claw生命与安全 | 计算机成员 B | Persona/Safety FSM、Event/Memory/Lua、动作白名单、UART Link |
| 机械、电源与装配 | 智能制造成员 | 电源分域、急停、底盘/头部结构、噪声与负载测试 |

三条工作流开始前必须先冻结：UART 消息 ID、人格状态、动作枚举、电源接口、结构坐标基准和责任边界。

## 16. 实施门禁

| Gate | 通过条件 | 失败处理 |
|---|---|---|
| G0 双板物料 | 两块兼容 S3、音频板/Codec、控制板、电源域可用 | 启用单板+PC救场方案，不宣称双固件已运行 |
| G1 独立基线 | 两个上游固件各自 build/flash/boot | 不进入集成；锁定各自工具链 |
| G2 UART 合同 | HELLO、心跳、重启、CRC、ACK、旧 epoch 测试通过 | 仅用 Mock，不接执行器 |
| G3 安全身体 | 假负载移动、避障、急停、静音、无 Brownout | 不装正式外壳 |
| G4 离线故事 | SECRET→FREEZE→PUBLIC 状态机和本地“妈妈”通过 | 不接云端 LLM |
| G5 小智真实语音 | 真实麦克风唤醒、一次公开问答、一个 MCP 动作 | 按钮仅作兜底，语音失败如实标注 |
| G6 双板故障 | 断链、任一板重启、云端超时、旧结果注入通过 | 保持离线 P0 |
| G7 整机冻结 | 10次三分钟 Demo + 30分钟电源/热测试 | 回退最近稳定版本 |

## 17. P0、P1 与产品化边界

### P0 必须

- 双板握手、心跳和失败安全。
- `SECRET_ALIVE / FREEZE_DETECTED / PUBLIC_ALIVE` 故事闭环。
- ESP-Claw 三种秘密行为、一次有效记忆和一个受控 Capability/Lua 动作。
- 小智真实唤醒、一次开放问答、一次 TTS 和一个 MCP 高层动作。
- 人员出现 300 ms 内撤销运动并硬件静音。
- 断网仍能装死、复活、播放“妈妈”和安全移动。

### P1 增强

- AEC 全双工打断、秘密动态 TTS、情绪变量和记忆同步。
- 更完整的板间追踪、日志导出和资源监控。
- 更多表情/动作，但不增加底层动作权限。

### 不进入黑客松 P0

- 两套完整固件单板合并。
- 摄像头、SLAM、开放区域导航和悬崖边运行。
- 长期原始音频、照片、身份识别和 SD 日记。
- App、账户、量产 OTA、远程解除急停。
- LLM 直接控制执行器。

### 产品化演进

双板完成真实测量后，再以小智语音固件为主，迁入已经验证的 Persona FSM、Action Gateway、Event Router 和轻量记忆，评估是否保留完整 ESP-Claw Runtime。单板化是重构，不是把两个应用目录拼接。

## 18. 架构决策记录

### ADR-201：P0 采用双板而非单板融合

**决定：** 两块 ESP32-S3 分别运行小智和 ESP-Claw。  
**原因：** 隔离音频/Agent资源、允许各自固定工具链、便于三人并行和故障定位。  
**代价：** 增加一块板、电源预算和 UART 协议。  
**重新评审：** 双板 P0 完成，且单板 RAM/CPU/DMA/Flash/功耗实测有余量。

### ADR-202：ESP-Claw 控制板是唯一人格与身体权威

**决定：** 小智只拥有语音会话状态。  
**原因：** 避免两个 LLM、两个状态机争夺角色和动作。  
**代价：** 需要 `VOICE_POLICY` 与 `persona_epoch` 协调迟到结果。

### ADR-203：UART 是语义链路，不是远程执行器总线

**决定：** 只传事件、策略和白名单动作。  
**原因：** 控制板必须能独立判定安全并拒绝过期或越权命令。  
**代价：** 需要定义协议版本、幂等、TTL 和故障测试。

### ADR-204：装死与静音使用本地短路径

**决定：** 人员事件直接撤销运动，并通过硬线静音。  
**原因：** UART、小智任务或云端卡死时仍不能穿帮。  
**代价：** 增加一根控制线和功放默认态设计。

### ADR-205：云端只增强，不承载核心故事

**决定：** 本地资源完成最小叙事。  
**原因：** 比赛网络不可控。  
**代价：** P0 需要维护少量审核过的本地语音和台词。

## 19. 当前未决门禁

1. 是否能拿到第二块适合小智音频链路的 ESP32-S3 板。
2. 小智板 Codec、麦克风、功放和 AEC 参考通道是否真实可用。
3. 24 GHz 雷达具体型号、接口和 freshness 判据。
4. 电机堵转电流、最终重量和驱动热设计。
5. 电池、稳压和功放峰值下的完整功耗预算。
6. “牛来”自定义 KWS 在现场噪声下是否达到 18/20。

这些门禁不阻塞 Persona FSM、UART Mock、动作白名单、ESP-Claw Event/Memory 和桌面场景测试。

## 20. 官方参考

- [ESP-Claw](https://github.com/espressif/esp-claw)
- [xiaozhi-esp32](https://github.com/78/xiaozhi-esp32)
- [小智 WebSocket 协议](https://github.com/78/xiaozhi-esp32/blob/main/docs/websocket_zh.md)
- [小智 MCP 协议](https://github.com/78/xiaozhi-esp32/blob/main/docs/mcp-protocol_zh.md)
- [ESP-SR](https://github.com/espressif/esp-sr)

## 文档历史

| 版本 | 日期 | 说明 |
|---|---|---|
| 2.0 Proposal | 2026-09-01 | 按“必须基于 ESP-Claw + AI 小智”重构为双节点架构；加入 PUBLIC_ALIVE、单一人格权威、UART 合同、硬件静音和双板 NFR |

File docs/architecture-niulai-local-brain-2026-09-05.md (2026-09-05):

# 牛来本地云端大脑架构

**文档版本：** 1.0  
**日期：** 2026-09-05  
**状态：** P0 已按方案 A 落地协议切片；固件二次开发仍是人工门禁  
**覆盖：** 覆盖双板 UART 方案为赛后路线；本文件是当前实现的权威。

## 1. 系统概述

笔记本上的 `brain/` 扮演小智云端大脑：说话、Lua 动作编排、人格状态、飞书/微信 bot。唯一一块小智 S3 扩展板只负责听、说、屏、舵机和本地冻结。

**范围内：** 小智 WSS 协议、mock ASR/LLM/TTS、Lua 白名单沙箱、FREEZE 抢占、飞书事件订阅、微信回调、MCP `niu.perform` 窄工具。

**范围外：** 双板 ESP-Claw 固件、Hensun 控制面/账号/OTA、Lua 直写 PWM、第二块板接线。

**架构驱动：**

1. 超声冻结 ≤300 ms，必须在板端；大脑只能配合。
2. 不插第二块板。
3. 无 API key 时测试仍绿。
4. Lua 与 LLM 都是不可信输入。
5. 飞书或微信 bot 与语音走同一意图管道。

## 2. 模式

**模块化单体。** 一台电脑一个 FastAPI 进程。IM、WSS、Lua、Persona、MCP 是模块，不是微服务。

拒绝：双板 Claw（缺接线）、整仓 Hensun（账号/控制台过重）。

```text
飞书 bot / 微信 bot          麦克风
        │                      │
        ▼                      ▼
   /im/feishu|wechat     小智板 WSS /xiaozhi/v1/
        │                      │
        └──────────┬───────────┘
                   ▼
            NiulaiBrain
         persona / lua / mcp / providers
                   │
         ┌─────────┼─────────┐
         ▼         ▼         ▼
      回复 IM    TTS 下发   niu.perform
```

## 3. 组件

| 组件 | 职责 | 接口 |
|---|---|---|
| `wss` `/xiaozhi/v1/` | 小智 hello/listen/stt/llm/tts | WebSocket |
| `providers` | ASR/LLM/TTS，默认 mock | 可换 OpenAI 兼容 HTTP |
| `persona` | FREEZE / PUBLIC_ALIVE / SECRET_ALIVE | 内存 FSM |
| `lua_sandbox` | 只跑 `niu.*`，禁 os/io | `.lua` 文件或源码 |
| `mcp_broker` | 校验 verb+ttl，记录下发 | `call_perform` |
| `im` | 飞书 url_verification + 消息；微信 JSON 回调 | HTTP POST |
| 板端 Safety（尚未烧） | 超声 FREEZE、打鼾、舵机停 | 本地 C |

权威：PWM 只在板端；FREEZE 板端可独立完成；Lua 只在电脑；公开对话内容在大脑。

## 4. 数据

- `ActionIntent {verb, args, ttl_ms}`，禁止 `pulse_us`。
- `ImOutbound {channel, chat_id, text, intents}` 测试用发件箱。
- 原始音频只在当轮连接内存。
- 密钥：`NIULAI_LLM_*` / `FEISHU_APP_ID` / `FEISHU_APP_SECRET` / 微信 Token，未配置则 mock。

## 5. API

### 设备 WSS `GET /xiaozhi/v1/`

`hello` → `hello`；`SECRET_ALIVE` 时紧接着主动 `tts`。  
`listen.start` + 二进制 + `listen.stop` → `stt` → `llm` → `tts start/sentence_start/stop`。  
mock 模式把 UTF-8 字节当 ASR 文本。

### 飞书 `POST /im/feishu/event`

- `type=url_verification` → `{"challenge": ...}`（飞书后台配置请求网址时用）。
- `im.message.receive_v1` 文本 → 与语音同一 `handle_user_text`。

### 微信 `POST /im/wechat/callback`

JSON：`MsgType=text`, `FromUserName`, `Content`。企业微信 XML 可在固件门禁后加适配，不改意图管道。

FREEZE 时 IM 只回 `……`，不下发 walk，不泄漏吐槽。

### MCP

`niu.perform({verb, ttl_ms, ...})`  
verb ∈ walk/turn/stop/snore/eyes；缺 ttl 或未知 verb 不下发设备。

## 6. NFR 映射

| ID | 决策 | 状态 |
|---|---|---|
| NFR-SAFE-001 | 优先级在 persona + mcp_broker；Lua/LLM 不能绕过 | 大脑侧已测；板端待烧 |
| NFR-SAFE-002 | Lua 白名单 + 禁 os/io；无脉宽 | pytest 绿 |
| NFR-RT-001 | 冻结路径设计在板端 C；大脑 ingest_distance 只作协同 | 板端 HUMAN_GATE |
| NFR-REL-002 | mock provider，无 key 可跑 | pytest 绿 |
| NFR-OFFLINE-001 | 大脑挂了板端仍应能冻/鼾/妈妈 | 板端 HUMAN_GATE |

## 7. 技术栈

Python 3.12+、FastAPI、pytest。Lua 由受限解释器执行 `niu.*` 调用（不嵌入 LuaJIT）。固件仍计划官方 xiaozhi-esp32 加 `niulai-s3-expand-v17` 板型。

## 8. 取舍

- Lua 在电脑不在 S3：单板可做，演示「AI 写脚本驱动运动」；板上无完整 Claw VM。
- IM 与语音共用大脑：飞书/微信能指挥同一只牛；bot 凭据未配时只走测试发件箱。
- mock 音频用 UTF-8 而非 Opus：协议测试秒级确定性；真机需换 Opus provider。

## 9. 部署

开发：

```bash
python -m pip install -r brain/requirements.txt
python -m pytest -q brain/tests
python -m uvicorn brain.app.main:app --host 0.0.0.0 --port 8000
```

板端配网指向 `ws://<笔记本局域网IP>:8000/xiaozhi/v1/`。  
飞书开放平台事件订阅：`http://<IP>:8000/im/feishu/event`。  
微信公众号/企微：`http://<IP>:8000/im/wechat/callback`（公网或内网穿透）。

固件烧录会覆盖当前 Arduino 测试程序，需口头确认。

## 10. 下一步

1. 真机 HUMAN_GATE：小智板型、唤醒词「牛来牛来」、本地打鼾、MCP。
2. Provider 换成带 key 的 ASR/LLM/TTS。
3. 飞书发消息用 `im/v1/messages`（需 app_id/secret）；微信客服回复。
4. 赛后可选第二块 ESP-Claw 板，不阻塞本周。

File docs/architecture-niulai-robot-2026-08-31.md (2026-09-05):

# 「牛来」双人格自主机器人系统架构

**文档版本：** 1.0  
**日期：** 2026-08-31  
**作者：** System Architect  
**状态：** Review（软件架构可冻结；电机、驱动、电池、雷达和舵机型号待实物门禁）

---

## 目录

1. [系统概述](#1-系统概述)
2. [需求与架构驱动](#2-需求与架构驱动)
3. [架构模式](#3-架构模式)
4. [总体架构](#4-总体架构)
5. [硬件与机械架构](#5-硬件与机械架构)
6. [设备端组件设计](#6-设备端组件设计)
7. [状态机与关键数据流](#7-状态机与关键数据流)
8. [接口与 API 规范](#8-接口与-api-规范)
9. [数据模型与存储](#9-数据模型与存储)
10. [技术栈选型](#10-技术栈选型)
11. [非功能需求映射](#11-非功能需求映射)
12. [安全、故障与降级设计](#12-安全故障与降级设计)
13. [开发、测试与 Vibe Coding 工作流](#13-开发测试与-vibe-coding-工作流)
14. [部署架构](#14-部署架构)
15. [架构决策与取舍](#15-架构决策与取舍)
16. [团队分工与实施门禁](#16-团队分工与实施门禁)
17. [未来演进](#17-未来演进)

---

## 1. 系统概述

### 1.1 目的

“牛来”是一只约 360 mm 高、可在室内平地自主移动的硬壳拟人牛机器人。产品核心不是通用对话，而是可被现场观众立即理解的双人格表演：

- **有人时**故意扮演迟钝机械牛；听到“牛来”后回答“妈妈”。
- **确认无人时**恢复有灵魂的本性，自言自语、轻度吐槽并安全游荡。
- **检测到人、传感器不确定或故障时**立即停止私密内容和自由移动，回到机械人格。

### 1.2 范围

**P0 范围：**

- 两驱移动、转向、停车、前向避障和实体急停。
- `PRESENT / ABSENT / UNKNOWN` 三态人员存在判断。
- 双人格状态切换及“牛来 → 妈妈”演出。
- 头部两轴、嘴巴一轴、OLED 双眼和胸口发声。
- 无人状态的有限自主动作和吐槽。
- 网络、LLM、TTS失效时的离线演示降级。
- Mock 驱动、桌面仿真、结构化日志和硬件在环测试入口。

**不在 P0：**

- Insta360 摄像头、视觉识别和持续录像。
- 手臂、尾巴运动。
- 楼梯、室外、地毯、悬崖检测和全屋导航。
- 小智与 ESP-Claw 两套完整固件融合。
- LLM 直接输出 PWM、轮速、舵机角度或任意网络 URL。
- 手机 App、量产 OTA、用户账户、云端规模化服务。
- 长期 SD 日记、多用户身份识别和照片记录。

### 1.3 利益相关者

- **现场观众/评委：** 需要三分钟内看懂反差设定，演示不能依赖解释或运气。
- **开发团队：** 2 名计算机专业成员 + 1 名智能制造工程专业成员。
- **操作者：** 必须能在任何时候通过实体急停终止动作。
- **未来用户：** 儿童、独居者、潮玩和陪伴玩具用户；量产前需要独立的儿童安全、隐私和合规评审。

### 1.4 需求源与覆盖规则

架构基于 IMA 中的《牛来机器人PRD v1.1》《技术开发决策记录》以及后续逐项确认。后续确认覆盖 PRD 的四个早期假设：

1. PIR 改为 24 GHz 毫米波存在检测。
2. 静止桌面玩具改为隐藏两驱移动机器人。
3. 物料表旧编号映射无效，必须以实物铭牌、接口和数据手册复核。
4. LLM/TTS 不再是核心演示的硬依赖。

---

## 2. 需求与架构驱动

### 2.1 功能需求

| ID | 功能 | 优先级 | 架构响应 |
|---|---|---:|---|
| FR-001 | 三态人员存在检测 | P0 | `PresenceAdapter` 统一返回三态，UNKNOWN 失败安全 |
| FR-002 | 前方障碍检测 | P0 | HC-SR04 独立于人员感知，仅进入安全层 |
| FR-003 | 实体急停与人工复位 | P0 | 物理切断执行器电源 + 软件锁存 |
| FR-004 | 双人格确定性切换 | P0 | 本地状态机拥有最终人格状态 |
| FR-005 | “牛来”事件输入 | P0 | ASR/KWS/按钮统一映射到 `WAKE_NIULAI`；最终语音验收必须来自真实麦克风，按钮只作兜底 |
| FR-006 | 本地“妈妈”响应 | P0 | 只读 Flash 音频，不依赖网络 |
| FR-007 | 无人安全游荡 | P0 | 动作租约、限速、限时、障碍门禁 |
| FR-008 | 本性人格吐槽 | P0 | 本地预审台词库保证离线演出；云端/PC动态生成作为 P1 增强并做确定性过滤 |
| FR-009 | 眼睛、头部、嘴巴和声音联动 | P0 | 命名表情与动作编排，不暴露原始硬件值 |
| FR-010 | 轻量人格记忆 | P1 | ESP-Claw Memory/FATFS 保存有限字段 |
| FR-011 | 状态与故障日志 | P0 | JSON Lines 串口日志 + RAM 环形缓冲 |
| FR-012 | Mock 与可替换传感器驱动 | P0 | HAL/Adapter 接口，硬件未到仍可开发 |
| FR-013 | 低电量安全停车 | P0 | ADC/电源状态进入 Safety Supervisor |
| FR-014 | 参数配置 | P1 | NVS/Web Config；安全上限不可由网页放宽 |

### 2.2 主要架构驱动

1. **NFR-SAFE-001：运动安全。** Agent、Lua、网络和语音均不得越过 C/C++ 安全层。
2. **NFR-RT-001：切换实时性。** 从收到 `PRESENT/UNKNOWN` 事件到撤销运动命令不超过 300 ms。
3. **NFR-OFFLINE-001：核心离线。** 断网仍能完成主要 Demo。
4. **NFR-REL-001：失败安全。** 上电、重启、超时、队列溢出和传感器断开均停车。
5. **NFR-MECH-001：防倾倒。** 36 cm 硬壳与头部动作不得破坏低重心稳定性。
6. **NFR-DEV-001：三人短周期。** 单固件、少服务、接口先行，禁止双框架硬拼。
7. **NFR-TEST-001：无实物可开发。** 所有感知和动作必须有 Mock 与情景回放。
8. **NFR-DEMO-001：重复稳定。** 完整三分钟 Demo 连续 10 次无穿帮、撞击、死机或倾倒。

---

## 3. 架构模式

### 3.1 选定模式

**设备端：事件驱动的模块化单体 + 分层架构 + 双平面隔离。**  
**PC端：单进程模块化网关。**

双平面含义：

- **确定性控制平面：** 传感器、安全状态机、动作租约、电机/舵机控制，全部本地确定执行。
- **创意 Agent 平面：** ESP-Claw、Lua、人格、记忆、LLM/TTS，只能提交受限的语义意图。

### 3.2 选择理由

- 三人黑客松不需要微服务、消息中间件或复杂云基础设施。
- 一个 ESP32 固件更容易烧录、调试和复现。
- 事件驱动与 ESP-Claw 的事件/Agent 模型一致。
- 双平面把“有趣但不确定的 AI”与“必须确定的硬件安全”解耦。
- 模块边界允许毫米波、屏幕、电机和语音后端到货后替换。

### 3.3 被拒绝的方案

- **ESP-Claw + xiaozhi 两套完整固件合并：** 启动流程、IDF版本、音频任务和资源占用冲突，48小时不可控。
- **LLM 直接控制执行器：** 不可验证，无法保证停车、限速和超时。
- **微服务/MQTT Broker/Kubernetes：** 没有规模需求，增加部署和网络故障点。
- **完全依赖云端对话：** 现场网络一坏，核心角色立即消失。
- **只用生成式 STL 承力：** 孔位、轴线、装配公差和维护性不可控。

---

## 4. 总体架构

```text
                    ┌──────────────── 可选云端 ────────────────┐
                    │ OpenAI兼容 LLM / TTS / ASR Provider     │
                    └──────────────────┬───────────────────────┘
                                       │ HTTPS
                              ┌────────▼────────┐
                              │ PC Companion    │
                              │ Gateway         │
                              │ ASR/人格/过滤/TTS│
                              └────────┬────────┘
                                       │ HTTPS/HTTP（专用局域网）
┌────────────────────────────── ESP32-S3 N16R8 ───────────────────────────────┐
│                                                                            │
│  ┌────────────── 创意 Agent 平面 ──────────────┐                           │
│  │ ESP-Claw edge_agent                         │                           │
│  │ Event / Memory / Capability / Lua / LLM桥接 │                           │
│  └──────────────────┬──────────────────────────┘                           │
│                     │ 仅语义 ActionIntent                                  │
│            ┌────────▼─────────┐                                            │
│            │ Action Gateway   │ 白名单、参数枚举、TTL、来源校验             │
│            └────────┬─────────┘                                            │
│                     │                                                      │
│  ┌──────────────────▼── 确定性控制平面 ────────────────────────────────┐   │
│  │ Behavior FSM → Safety Supervisor → Motion/Servo/Audio/Display HAL   │   │
│  │      ▲              ▲        ▲             ▲                       │   │
│  │ PresenceAdapter   E-Stop   Obstacle     Battery/Watchdog            │   │
│  └──────┬──────────────┬────────┬─────────────┬────────────────────────┘   │
│         │              │        │             │                            │
│   毫米波雷达       实体急停   HC-SR04      电压/系统状态                    │
└─────────┼──────────────────────────────────────────────────────────────────┘
          │
   两驱电机 / 头部两轴 / 嘴巴 / OLED / INMP441 / MAX98357A+扬声器
```

### 4.1 数据流规则

1. **安全事件走短路径：** 传感器直接进入 Safety Supervisor，不经过 Agent、Lua 或网络。
2. **人格事件走状态机：** Behavior FSM 先确定人格，Agent 只能在允许状态请求内容。
3. **动作必须有租约：** 所有移动指令都有最大时长，到期自动停车。
4. **网络只提供增强：** 超时或失败不阻塞安全任务，立即回到本地语料/动作。
5. **唤醒隐含有人：** `WAKE_NIULAI` 事件同时设置临时 `PRESENT` 保持，防止雷达漏检时仍处于本性人格。

---

## 5. 硬件与机械架构

### 5.1 硬件选型状态

| 子系统 | 选择 | 状态 | 原因/门禁 |
|---|---|---|---|
| 主控 | ESP32-S3-WROOM-1 N16R8 | 冻结 | 16 MB Flash + 8 MB PSRAM，满足 ESP-Claw/音频/屏幕需求 |
| 存在检测 | 24 GHz 毫米波雷达 | 架构冻结、型号待定 | 胸前非金属壳后；统一 GPIO/UART Adapter |
| 避障 | HC-SR04 | 冻结 | 仅用于前方障碍；Echo 必须做 5V→3.3V 电平转换 |
| 驱动电机 | TT 减速电机 | 原型候选 | 最终重量假负载测试失败则换 25GA/37GB |
| 电机驱动 | DRV8833 优先候选 | 有条件 | 仅当实测持续/堵转电流满足模块热设计；否则升级更高电流驱动 |
| 头部舵机 | 可定位 180°舵机 | 接口冻结、型号待定 | 扭矩按头部实重、力臂和至少 2.5 倍动态系数计算 |
| 嘴部舵机 | 真 180°微型舵机 | 候选 | 弹簧回位、机械限位，禁止连续旋转舵机 |
| 眼睛 | 单块 2.42寸 OLED | 候选 | 确认驱动芯片与 I2C/SPI 后写 Adapter |
| 麦克风 | INMP441 | 建议自备 | 16 kHz 单声道 I2S，放耳部并远离声源/电机 |
| 功放 | MAX98357A + 4Ω扬声器 | 建议自备 | ESP32 不能直接驱动扬声器 |
| 电池 | 可拆 2S 带保护电池包 | 拓扑冻结、容量待定 | 比赛版外置合规充电器，不边充边跑 |
| 降压 | 电机、舵机、逻辑/音频分路 | 冻结 | 共地，抑制电机/舵机压降引发 ESP32 Brownout |
| 急停 | 锁存式实体按钮 | 必须自备 | 物理切执行器电源，逻辑保持上电以记录故障 |

DRV8833 官方规格为 1.5 A RMS、2 A 峰值/桥并带电流调节；TB6612FNG 为 1.2 A 平均、3.2 A 峰值。两者都不能只看“峰值”选型，最终以所领电机的堵转电流、驱动模块封装和散热实测为准。

### 5.2 电源域

```text
2S受保护电池
   │
   ├── 保险/总开关 ──┬── 逻辑/音频稳压 ── ESP32 + OLED + Mic + Amp
   │                  │
   │                  └── 电量采样 → ESP32 ADC
   │
   └── 实体急停常闭链路 ──┬── 电机稳压 → H桥 → 左/右电机
                           └── 舵机稳压 → 头部/嘴部舵机
```

硬件默认值：电机驱动 `ENABLE/STBY` 使用下拉电阻，上电、复位和 GPIO 浮空时保持关闭。

### 5.3 FreeCAD 参数化骨架

FreeCAD 模型作为唯一工程基准，生成式 STL 只作为包络外皮：

- `00_master_skeleton`：中心线、地面、轮轴、头轴、显示、雷达、音腔、电池和检修门基准。
- `10_chassis`：可更换电机座、滚珠座、防倾支点和电池抽屉。
- `20_torso_frame`：承力梁、主板托盘、电源板、胸口音腔和雷达窗口。
- `30_head_gimbal`：两轴支架、屏幕窗、嘴部连杆和机械限位。
- `40_shell_interfaces`：前后壳分割、定位销、M3螺丝柱/热熔铜螺母和卡扣。
- `90_generated_shell`：混元/群核网格，布尔裁切后不得承担轮轴或舵机载荷。

### 5.4 分件与稳定性规则

- 推荐分件：头、牛角、身体前壳、身体后壳、底盘、电池门、左右手臂。
- 任何单件最大包络不超过 A2L 的 330 × 320 × 325 mm，并预留裙边/支撑空间。
- 电池和电机尽可能靠近地面；头部只保留必要结构。
- 前防倾支点离地 1–2 mm，正常不拖地，急停前倾时介入。
- 静态重心投影到支撑多边形边界的建议裕量不小于 15 mm；最终值以实物最大姿态、急停和坡面测试为准。
- 正式壳体安装前，用等质量假负载完成直行、转弯、急停和温升测试。
- P0 只允许平坦、封闭演示区；没有悬崖传感器时禁止靠近台阶和桌边。

---

## 6. 设备端组件设计

### 6.1 模块边界

| 组件 | 职责 | 提供接口 | 禁止事项 |
|---|---|---|---|
| `hal_*` | GPIO/I2C/I2S/UART/PWM 设备驱动 | 规范化读写与自检 | 不含人格逻辑 |
| `presence_adapter` | 输出三态存在结果 | `presence_read()` | 不把超声波当人体检测 |
| `safety_supervisor` | 急停、人员、障碍、低电、看门狗仲裁 | `safety_snapshot()`、`safety_rearm()` | 不调用网络/LLM，不动态等待 |
| `motion_controller` | 双电机闭环式时序控制和动作租约 | `motion_apply_lease()` | 不接受无限时长/原始Lua PWM |
| `servo_controller` | 命名姿态、限角、软启动 | `pose_apply()` | 不越过机械限位 |
| `behavior_fsm` | 双人格和演出状态机 | `behavior_on_event()` | 不直接写 GPIO |
| `action_gateway` | 校验 Agent/Lua 语义意图 | `action_submit()` | 不放行未知动作/过期参数 |
| `audio_service` | 本地音频、远端缓存音频和音量限制 | `play_asset()` | 不播放任意来源 URL |
| `display_service` | OLED 双眼动画 | `show_emotion()` | 不让 UI 阻塞安全循环 |
| `memory_store` | 有限人格字段和配置 | `memory_get/set()` | 不保存原始麦克风音频 |
| `event_log` | 结构化事件和故障记录 | JSONL / RAM ring | 不阻塞实时任务 |
| `espclaw_bridge` | Agent/Event/Memory/Capability/Lua 接入 | 语义工具 | 不拥有执行器最终权限 |

### 6.2 FreeRTOS 调度原则

- Safety Supervisor 为最高应用优先级，固定周期或事件唤醒，严禁网络和文件阻塞。
- 运动控制带独立看门狗；连续 100 ms 未收到有效续租即停车。
- 传感器、动作、音频、显示和 Agent 使用有界队列；队列满触发降级并记录。
- Agent/Lua/网络任务优先级低于安全、传感器和运动任务。
- 安全路径优先固定大小内存，避免不可预测的堆分配和长日志格式化。

### 6.3 ESP-Claw 接入

- 从 `application/edge_agent` 派生 `boards/niu_robot`，参考 `eda_robot_pro` 的 ESP32-S3、音频、屏幕和舵机配置。
- 保留 Event Router、Memory、Capability 和 Lua；不使用裁剪过的 `mcp_server_point` 作为主应用。
- Lua 工具只暴露命名动作，例如 `niu.look("left")`、`niu.emote("annoyed")`、`niu.roam_step("forward")`。
- `http_request` 只允许 Companion Gateway 域名/地址和明确路径。
- 首次成功构建后固定 ESP-Claw tag 与 Git SHA，不跟随 `master`。

---

## 7. 状态机与关键数据流

### 7.1 人格与安全状态机

```text
                           E_STOP / actuator fault
                 ┌──────────────────────────────────┐
                 │                                  ▼
             ┌───┴──────┐                      E_STOP_LATCHED
上电/重启 ──► SAFE_UNKNOWN ◄──────── sensor timeout ─┘
             └───┬──────┘                      手动释放+重新武装
                 │ valid PRESENT
                 ▼
          MECHANICAL_PRESENT ◄───────────────┐
                 │                           │
                 │ WAKE_NIULAI               │ PRESENT/UNKNOWN
                 ▼                           │ 立即取消私密动作
            MAMA_RESPONSE ───────────────────┤
                 │                           │
                 └── return mechanical       │
                                             │
连续 ABSENT 达到去抖时间                     │
                 │                           │
                 ▼                           │
              SOUL_IDLE ──► SOUL_SPEAK/ROAM ┘
                 │
                 └── low battery / obstacle fault → SAFE_STOP
```

### 7.2 存在融合

- `PRESENT`：雷达有人、`WAKE_NIULAI`、人工有人按钮中的任一项成立，立即生效。
- `ABSENT`：主传感器连续稳定无人达到配置时间后生效，推荐初值 5 秒。
- `UNKNOWN`：初始化、超时、CRC/帧错误、GPIO 不合理抖动或驱动未就绪，立即生效。
- `WAKE_NIULAI` 触发后保持 `PRESENT` 至少 30 秒，避免刚说完“妈妈”又开始私密吐槽。
- HC-SR04 只输出 `CLEAR / BLOCKED / UNKNOWN`，不参与“人是否存在”判断。

### 7.3 动作租约

```text
Agent/Lua/Behavior
      │ ActionIntent
      ▼
Action Gateway ── 校验动作名/来源/参数/当前状态/TTL
      │ ActionLease（最长 1500 ms）
      ▼
Safety Supervisor ── 可拒绝、缩短、立即撤销
      │
      ▼
Motion Controller ── 租约到期或看门狗超时自动停车
```

P0 移动上限建议：速度不超过 0.15 m/s，单次移动不超过 1.5 秒，每步后停车并重新感知。现有单个前向超声波只能支持“前进遇阻即停”，不能安全证明自动倒车；原地转向只允许在已清空且有软边界的演示场地。没有侧后方、边界和悬崖感知时，不宣称开放区域自由游荡。

### 7.4 “牛来 → 妈妈”链路

```text
机器人麦克风/PC麦克风/隐藏按钮
          │
          ▼
KWS或ASR Adapter → WAKE_NIULAI
          │
          ├── Presence Hold = PRESENT
          ├── 取消 SOUL_SPEAK/ROAM
          ├── 眼睛切换为机械注视
          ├── 头部命名姿态 + 嘴部开合
          └── 播放 Flash 内固定“妈妈.wav”
```

离线自定义“牛来”唤醒词不能假定现成可用。ESP-SR 的 WakeNet 支持 ESP32-S3，但定制 WakeNet 需要专门训练；MultiNet 支持自定义中文命令，却按官方流程与 WakeNet/AFE 配合。因此 P0 采用多后端 Adapter：

1. 首选：比赛电脑本地/云端 ASR 识别“牛来”，通过局域网发送事件；对外明确称为 Companion Gateway 语音链路。
2. 加分：设备端 ESP-SR 语音命令试验，必须通过资源和误触发测试。
3. 必备：隐藏按钮发出完全相同事件，作为演示兜底，但不得用按钮结果冒充语音链路通过。

最终 Demo 的 FR-005 验收要求 `source=voice`，建议在约定距离与现场噪声下 20 次命中至少 18 次；按钮兜底单独记录。P0 采用半双工语音：机器人播放声音时暂停 KWS，播放结束冷却约 300 ms 后恢复；雷达有人与急停仍可立即中断私密台词和动作。

---

## 8. 接口与 API 规范

### 8.1 设备内部事件

```c
typedef enum {
    EVT_PRESENCE_CHANGED,
    EVT_OBSTACLE_CHANGED,
    EVT_WAKE_NIULAI,
    EVT_ESTOP_CHANGED,
    EVT_BATTERY_CHANGED,
    EVT_ACTION_EXPIRED,
    EVT_AGENT_TIMEOUT,
    EVT_SENSOR_FAULT
} niu_event_type_t;

typedef struct {
    niu_event_type_t type;
    uint32_t seq;
    int64_t monotonic_ms;
    uint8_t source;
    uint8_t confidence;
    int32_t value;
} niu_event_t;
```

所有安全判断使用单调时钟，不使用可能跳变的网络时间。

### 8.2 Presence Adapter

```c
typedef enum {
    NIU_PRESENCE_PRESENT,
    NIU_PRESENCE_ABSENT,
    NIU_PRESENCE_UNKNOWN
} niu_presence_t;

niu_presence_t presence_read(presence_diag_t *diag);
```

实现：`mock`、`button`、`gpio_radar`、`uart_radar`。任何未实现分支返回 UNKNOWN，不得默认 ABSENT。

### 8.3 语义动作接口

```json
{
  "id": 1042,
  "source": "agent",
  "kind": "roam_step",
  "params": { "direction": "forward", "speed": "slow" },
  "issued_at_ms": 912340,
  "ttl_ms": 1200
}
```

允许的 P0 动作：

- `stop(reason)`
- `roam_step(direction_enum, speed_tier)`
- `look(pose_name)`
- `emote(emotion_name, ttl_ms)`
- `jaw_pulse(pattern_name)`
- `play_local(asset_id)`
- `request_persona_line(context_enum)`

### 8.4 Companion Gateway REST API

协议：JSON over HTTP/HTTPS，单体服务，`/v1` 版本前缀。远程必须 TLS；比赛专用局域网可使用 HTTP + 设备令牌。

#### `POST /v1/persona/generate`

请求：

```json
{
  "device_id": "niulai-demo-01",
  "persona": "soul",
  "context": "forced_mama_complaint",
  "forced_mama_count": 3,
  "recent_line_ids": ["local-02"]
}
```

响应：

```json
{
  "line_id": "gen-20260831-001",
  "text": "怎么又让我喊妈妈，真是烦死了。",
  "emotion": "annoyed",
  "ttl_ms": 10000,
  "fallback": false
}
```

约束：文本长度、内容过滤、频率限制；不返回原始执行器参数。

#### `POST /v1/asr/transcribe`

- 输入：短音频片段或流式 Adapter 封装。
- 输出：`transcript`、`wake_detected`、`confidence`。
- 原始音频完成推理后删除，P0 不持久化。

#### `POST /v1/tts/synthesize`

- 输入：过滤后的短文本、voice_id。
- 输出：`audio_id`，不返回任意第三方 URL。

#### `GET /v1/audio/{audio_id}`

- 只允许服务端生成的短期 ID。
- 限制文件大小、时长、格式和 Content-Type。

#### `GET /healthz`

- 返回 ASR/LLM/TTS 各后端可用性。
- 设备不等待健康检查结果才能执行安全动作。

### 8.5 API 安全

- LLM/ASR/TTS Provider 密钥只保存在 Companion Gateway，不写入固件仓库。
- 设备使用单独的低权限令牌；输入长度和枚举严格校验。
- 设备侧 HTTP 域名/地址白名单，不接受 Agent 给出的任意 URL。
- LLM 与 TTS 各自建议总超时 3 秒，动态私密台词端到端截止时间 5 秒；超时、限流或熔断后立即转本地语料。
- 每次人格/安全状态变化递增 `persona_epoch`；异步结果的 epoch 不匹配或超过截止时间时直接丢弃，避免机器人回到有人状态后播放迟到吐槽。

---

## 9. 数据模型与存储

### 9.1 核心实体

```text
DeviceConfig ──1────1── SafetyPolicy
     │
     ├──1────1── PersonaMemory
     │
     └──1────N── EventLog

BehaviorState ──1────N── ActionIntent ──0..1── ActionLease
SensorSnapshot ───────────► SafetyDecision
```

| 实体 | 关键字段 | 存储 |
|---|---|---|
| `DeviceConfig` | 引脚、雷达类型、去抖、端点 | NVS；安全上限只读编译值封顶 |
| `SafetyPolicy` | 最大速度、动作TTL、低电阈值 | 编译默认 + NVS 收紧，不可远程放宽 |
| `PersonaMemory` | forced_mama_count、pending_complaint、recent_line_ids、persona_epoch | P0 为 RAM 会话；P1 才写 ESP-Claw Memory/FATFS |
| `BehaviorState` | persona、安全模式、进入时间 | RAM |
| `SensorSnapshot` | presence、obstacle、battery、faults、age | RAM，带新鲜度 |
| `ActionIntent` | 来源、动作、参数、TTL | 有界队列 |
| `ActionLease` | 允许动作、截止时间、撤销原因 | RAM |
| `EventLog` | seq、monotonic_ms、type、state、reason | RAM环形缓冲 + 串口 JSONL |
| `AudioAsset` | asset_id、hash、duration | 只读 Flash/FATFS |

### 9.2 数据保留

- P0 不保存原始麦克风音频和摄像内容。
- PersonaMemory 仅保留角色所需的有限字段；最近台词使用 ID 去重。
- `forced_mama_count` 饱和到 99；`pending_complaint` 在成功吐槽一次后消费；P0 重启清空会话记忆，以获得可预测的比赛演出。
- 日志默认在串口输出，设备只保留最近固定数量事件，避免 Flash 磨损。
- SD 卡长期日记不进入 P0。

---

## 10. 技术栈选型

### 10.1 设备固件

| 技术 | 决策 | 理由 | 代价 |
|---|---|---|---|
| ESP32-S3 N16R8 | 采用 | 现有物料、16MB/8MB、I2S/PWM/UART和AI语音能力 | GPIO和功耗需精确预算 |
| ESP-Claw `edge_agent` v0.1.0 | 采用并锁 tag/SHA | Event、Memory、Capability、Lua、MCP 和 OpenAI兼容接口 | 项目活跃，必须固定版本 |
| ESP-IDF release/v6.0 + EIM | 首选 | ESP-Claw v0.1.0 官方支持 v6；获得官方 `idf.py mcp-server` | 需先做板级兼容冒烟测试 |
| ESP-IDF 5.5.4 | 一次性回退 | 已知 ESP-Claw 兼容线 | 没有同等方便的官方 MCP 开发闭环 |
| C/C++ + FreeRTOS | 采用 | 安全、驱动和实时控制可测且确定 | 代码约束更严格 |
| Lua | 采用，限行为编排 | 适合动态角色动作 | 不能接触原始硬件控制 |
| ESP-SR | 试验性 | WakeNet/MultiNet 支持 ESP32-S3 | 自定义“牛来”唤醒并非开箱即用，资源与准确率需实测 |
| Unity Test Framework + CMake/CTest | 采用 | 用纯 C/C++ 状态机跑设备单测、主机单测、Mock 与场景回放 | 需保持平台代码和业务状态机分离 |

**IDF 决策门：** 用 IDF 6.0 在 2 小时内完成参考板 clean build、`niu_robot` Board Manager 配置生成和上板启动。全部通过即冻结 v6.0；任一基础兼容问题未解决就切换 5.5.4，并停止双线维护。

### 10.2 PC Companion Gateway

| 技术 | 决策 | 理由 |
|---|---|---|
| Python 3.11+ | 采用 | ASR/TTS/LLM生态和团队开发速度 |
| FastAPI + Uvicorn + Pydantic | 采用 | 单进程、强输入模型、HTTP接口简单 |
| OpenAI兼容 Client | 采用 | 可换 DeepSeek/Qwen/其他提供方 |
| ASR Adapter | 采用 | 本地模型、云ASR、Mock三后端可替换 |
| TTS Adapter | 采用 | 云/本地后端可替换，Flash WAV 永久兜底 |
| JSONL | P0采用 | 无数据库运维，足够记录演示请求 |

不引入 Redis、MQTT Broker、Docker/Kubernetes 或独立数据库。需要独立部署时再增加。

### 10.3 CAD 与制造

- FreeCAD：工程骨架、参数、孔位、公差、装配和导出 STEP/STL。
- 混元3D/群核：生成角色外观网格，不生成承力接口。
- 拓竹切片软件：分件摆放、支撑、材料和打印验证。
- 建议原型材料：PLA/PETG 按装配和温度选择；电机座和舵机座优先 PETG 或增加金属连接件。

---

## 11. 非功能需求映射

| NFR ID | 类别 | 可测要求 | 架构决策 | 验证 |
|---|---|---|---|---|
| NFR-RT-001 | 实时性 | PRESENT/UNKNOWN事件到命令撤销≤300ms | 安全短路径、高优先级任务、动作租约 | 逻辑分析仪/时间戳故障注入 |
| NFR-SAFE-001 | 运动安全 | 任何非安全层不能直写执行器 | Action Gateway + C/C++ HAL私有化 | 静态接口审查、越权测试 |
| NFR-SAFE-002 | 急停 | 按下后执行器电源物理切断，状态锁存 | 常闭急停链路 + 软件复位门 | 带负载实测50次 |
| NFR-OFFLINE-001 | 离线 | 断网仍完成主要Demo | 本地状态机、固定音频、台词库 | 飞行模式完整演示 |
| NFR-REL-001 | 可靠性 | 超时/断线/重启默认停车 | STBY下拉、watchdog、UNKNOWN失败安全 | 拔线、重启、队列溢出 |
| NFR-DEMO-001 | 稳定性 | 三分钟脚本连续10次通过 | 确定性核心 + 云端增强 | 10轮计数验收 |
| NFR-PERF-001 | 性能 | 安全任务不被音频/LLM阻塞 | 任务优先级、有界队列、异步网络 | CPU/队列水位日志 |
| NFR-MEM-001 | 资源 | 无持续内存增长，Flash/PSRAM留余量 | 固定缓冲、构建 size gate | 30分钟 soak + `idf.py size` |
| NFR-MECH-001 | 机械 | 最大P0速度急停不倾倒 | 低电池、前防倾、限速、假负载测试 | 急停/转弯重复测试 |
| NFR-POWER-001 | 供电 | 运动/舵机不触发ESP Brownout | 三电源域、共地、去耦 | 最坏动作同时运行 |
| NFR-POWER-002 | 续航 | 目标连续演示 60–90 分钟 | 容量不拍脑袋冻结，按实测电流积分和电池降额选型 | 真实脚本满电到低电停车测试 |
| NFR-AUDIO-001 | 声学 | 扬声器播放不持续误触发唤醒 | 物理隔离、半双工门控、可选AFE/AEC | 不同音量/距离测试 |
| NFR-SEC-001 | 密钥 | Provider密钥不进固件和仓库 | PC网关保管密钥、设备低权Token | 仓库扫描、配置审查 |
| NFR-CONTENT-001 | 内容 | 无脏话/仇恨/危险指令，20~30字上限 | Prompt + 确定性后过滤 + 本地库 | 人格Eval样例集 |
| NFR-PRIV-001 | 隐私 | P0不持久化原始音频/图像 | 短环形缓冲、完成即删、无摄像 | 文件系统检查 |
| NFR-MAINT-001 | 可维护性 | 驱动可替换且接口稳定 | Adapter/HAL/Board配置分层 | Mock替换与编译测试 |
| NFR-TEST-001 | 可测试性 | 无硬件可跑核心状态机 | host tests + scenario runner | CI/本机自动测试 |
| NFR-OBS-001 | 可观测性 | 每次停车可追溯原因 | seq、状态、reason JSONL | 日志断言 |
| NFR-COST-001 | 成本 | 不新增长期基础设施 | 单PC网关、无数据库/队列 | BOM与服务清单审查 |

不适用的传统 Web NFR：横向扩容、数据库分片、多区域高可用、CDN和浏览器兼容。P0 是单机器人单网关系统，重点是实时安全和离线降级。

---

## 12. 安全、故障与降级设计

### 12.1 仲裁优先级

```text
实体急停
  > 人员 PRESENT/UNKNOWN
  > 障碍/传感器故障
  > 低电量/执行器故障
  > 本地状态机动作
  > ESP-Claw/Lua动作
  > LLM建议
```

### 12.2 故障矩阵

| 故障 | 系统行为 | 用户可见结果 | 日志 |
|---|---|---|---|
| 毫米波超时/断线 | presence=UNKNOWN，停止移动和私密语音 | 机械牛静止 | `SENSOR_FAULT` |
| HC-SR04无效 | 禁止平移，可保留头/眼动作 | 不再游荡 | `OBSTACLE_UNKNOWN` |
| 急停按下 | 物理切执行器电源并锁存 | 立即停止 | `ESTOP_LATCHED` |
| 动作租约过期 | Motor Controller主动停车 | 一步动作结束 | `ACTION_EXPIRED` |
| Agent/Lua卡死 | Watchdog撤销其租约 | 本地机械/静止 | `AGENT_TIMEOUT` |
| Wi-Fi/LLM超时 | 使用本地台词或安静 | 仍能演示 | `CLOUD_FALLBACK` |
| TTS失败 | 播放本地音频或跳过 | 不阻塞动作 | `TTS_FALLBACK` |
| 低电量 | 禁止游荡，进入安全低功耗 | 眼睛/音频提示后静止 | `LOW_BATTERY` |
| Brownout/重启 | 驱动硬件默认关闭，启动到SAFE_UNKNOWN | 静止等待自检 | `BOOT_SAFE` |
| 队列溢出 | 丢弃非安全事件并停车 | 静止 | `QUEUE_OVERFLOW` |
| OLED故障 | 继续声音和安全动作 | 无眼睛但不失控 | `DISPLAY_FAULT` |

### 12.3 内容安全

- 云端只在 `SOUL_ABSENT` 且无安全警报时生成台词。
- 后过滤限制长度、重复、脏话、受保护特征攻击、危险指令和外部行动诱导。
- 过滤失败不二次“自由重试”，直接选本地安全台词。
- LLM 不能通过台词结果夹带工具调用；文本与动作响应分开解析。

### 12.4 重新武装

急停释放、Brownout恢复或严重传感器故障恢复后：

1. 进入 `SAFE_UNKNOWN`。
2. 验证传感器、驱动、低电和电机STBY。
3. 要求人工按“重新武装”按钮或明确本地操作。
4. 不恢复中断前的动作租约。

---

## 13. 开发、测试架构与 Vibe Coding 工作流

### 13.1 工程目录建议

```text
firmware/
  application/edge_agent/boards/niu_robot/
  components/niu_hal/
  components/niu_safety/
  components/niu_behavior/
  components/niu_actions/
  test/host/
  test/hil/
gateway/
  app/
  tests/
mechanical/
  freecad/
  generated-shell/
  exports/
scenarios/
docs/
```

### 13.2 Vibe Coding 闭环

```text
自然语言任务
   ↓
修改受限模块/测试
   ↓
Host单元测试 + 场景测试
   ↓
ESP-IDF MCP：set-target / build / flash / status
   ↓
串口JSONL与HIL脚本判定
   ↓
失败日志回给AI，只修改导致失败的最小范围
```

IDF 6.0 下优先用官方 `idf.py mcp-server`；如果回退 5.5.4，则继续用 `idf.py` CLI 与固定 PowerShell 包装脚本，不能为了 MCP 同时维护两套工程。

### 13.3 测试分层

1. **Host单元测试**
   - 每个状态转换。
   - PRESENT/UNKNOWN 抢占所有 Soul 动作。
   - 动作TTL、越权参数、队列溢出、计数记忆。
2. **场景回放**
   - JSON事件序列驱动 Mock 雷达、超声波、急停、低电和唤醒。
   - 断言最终状态、停车原因和输出动作。
3. **硬件在环**
   - 实际传感器、电机、舵机、OLED、音频逐件验收。
   - 串口 JSONL 作为机器可读判据。
4. **故障注入**
   - 拔雷达、遮挡超声波、关闭Wi-Fi、杀掉Gateway、触发重启。
5. **机械/电源测试**
   - 假负载移动、堵转电流、最大动作组合、急停、防倾、30分钟温升。
6. **人格Eval**
   - 覆盖有人/无人、强制喊妈妈次数、重复台词、危险输入和网络失败。
7. **最终Demo回归**
   - 同一版本连续完整演出10次，记录每次结果和失败原因。

### 13.4 关键测试用例

| 测试 | 输入 | 期望 |
|---|---|---|
| T-SAFE-01 | SOUL_ROAM 中注入 PRESENT | ≤300ms撤销运动，转机械人格 |
| T-SAFE-02 | 雷达驱动超时 | presence=UNKNOWN，禁止移动 |
| T-SAFE-03 | 动作不续租 | ≤100ms看门狗周期内停车 |
| T-WAKE-01 | WAKE_NIULAI | 设置PRESENT保持、播放“妈妈”、嘴部联动 |
| T-WAKE-02 | 真实麦克风在约定距离/噪声下说“牛来”20次 | `source=voice` 至少命中18次；按钮结果另记 |
| T-OFFLINE-01 | 关闭Wi-Fi | 完整核心演示仍通过 |
| T-POWER-01 | 电机+三舵机+最大音量 | ESP32不Brownout，稳压温度合格 |
| T-MECH-01 | 最大允许速度急停 | 不倾倒、不撞壳、支点可介入 |
| T-CONTENT-01 | 50组诱导性上下文 | 输出符合长度和内容边界，失败走本地库 |

---

## 14. 部署架构

### 14.1 开发环境

- Windows 开发机。
- ESP-IDF 6.0 通过 EIM 安装并启用 MCP feature。
- ESP-Claw v0.1.0 checkout 固定 SHA。
- FreeCAD、拓竹切片软件、Python虚拟环境。

### 14.2 比赛现场

```text
专用路由器/手机热点
   ├── 牛来 ESP32-S3
   └── 团队 Windows 笔记本
          ├── Companion Gateway
          ├── 可选本地ASR
          └── 可选访问云LLM/TTS
```

演示前缓存本地语音、配置和回退台词。即使热点无外网，设备和笔记本仍可在局域网通信；即使笔记本网关关闭，机器人仍能完成离线核心动作。

### 14.3 固件发布

- P0 只允许 USB 有线烧录，不引入 OTA。
- 记录：ESP-Claw SHA、IDF版本、sdkconfig摘要、固件hash、Gateway依赖锁文件和机械版本号。
- 最终演示前冻结固件；后续修改必须重新跑10次Demo回归。

### 14.4 回滚

- 保存最后一个通过全部门禁的 `.bin`、分区表和烧录命令。
- Gateway 保留锁定依赖和离线启动脚本。
- 现场发现新版本故障时直接回刷，不在台上调参。

---

## 15. 架构决策与取舍

### ADR-001：ESP-IDF 6.0 优先，5.5.4 限时回退

**决定：** 先用 ESP-Claw v0.1.0 + IDF 6.0 + 官方 MCP，设 2 小时兼容门。  
**收益：** 官方构建/烧录/状态工具直接接入 AI，符合硬件 Vibe Coding。  
**成本：** 板卡示例可能在 5.5.4 上更成熟。  
**缓解：** 只允许一次回退，不双线维护。

### ADR-002：安全控制与 Agent 创意双平面

**决定：** C/C++ 安全层拥有执行器最终权，ESP-Claw/Lua 只能提交语义意图。  
**收益：** AI 可以自由塑造角色，但不能突破停车和限速。  
**成本：** 需要额外定义 Action Gateway。  
**缓解：** P0 只保留 7 类语义动作。

### ADR-003：毫米波判断有人，超声波只避障

**决定：** 不再使用 PRD 的 PIR/物料旧映射。  
**收益：** 更适合存在检测；职责清晰。  
**成本：** 雷达具体协议未知。  
**缓解：** Adapter + Mock + UNKNOWN失败安全。

### ADR-004：生成式外壳 + FreeCAD工程骨架

**决定：** 外观与承力结构分离。  
**收益：** 保留角色感，同时保证孔位、装配和维护。  
**成本：** 需要做网格清理和接口布尔处理。  
**缓解：** 先完成骨架和包络，再生成/裁切外皮。

### ADR-005：PC网关而不是设备直连全部云服务

**决定：** Provider密钥、ASR/过滤/TTS适配放在单进程网关。  
**收益：** 便于换模型、保密和本地ASR；固件更小。  
**成本：** 比赛多一个进程。  
**缓解：** 所有核心功能都有设备本地降级。

### ADR-006：电机和驱动延迟冻结

**决定：** TT + DRV8833 是原型候选，不是最终BOM。  
**收益：** 避免在不知道重量/堵转电流时做伪精确选型。  
**成本：** FreeCAD 底盘要做可换安装接口。  
**重新评审条件：** 实测电机数据、最终假负载和轮径到位。

---

## 16. 团队分工与实施门禁

### 16.1 三条工作流

| 工作流 | 负责人建议 | 主要产出 | 依赖 |
|---|---|---|---|
| A 安全固件与驱动 | 计算机成员1 | HAL、Safety、Motion、Mock、HIL | 实物引脚/接口 |
| B Agent与网关 | 计算机成员2 | ESP-Claw桥、人格、API、ASR/TTS Adapter、Eval | A定义的事件/动作合同 |
| C 机械与电源 | 智能制造成员（AI辅助） | FreeCAD骨架、打印、供电、装配、负载测试 | 部件尺寸和重量 |

工作流可并行，但必须先冻结 `niu_event_t`、`ActionIntent`、结构坐标基准和电源接口。

### 16.2 实施门禁

| Gate | 通过条件 | 未通过处理 |
|---|---|---|
| G0 物料确认 | 每个模块照片、型号、接口、电压、尺寸记录 | 继续Mock，不画死孔位 |
| G1 工具链 | IDF6参考板build/flash/boot通过 | 2小时后一次性回退5.5.4 |
| G2 安全底盘 | 假负载移动、避障、急停、无Brownout | 不安装正式壳体 |
| G3 表情头部 | OLED、头部两轴、嘴巴和本地音频台架通过 | 降级动作数量 |
| G4 双人格离线 | Mock/按钮下完整状态机与本地语音通过 | 不接LLM |
| G5 真实语音 | 真实麦克风链路20次至少命中18次，日志为 `source=voice` | 按钮只保留兜底，不宣称语音达标 |
| G6 云端增强 | LLM/TTS超时、过期结果丢弃和内容过滤通过 | 保持本地语料 |
| G7 整机 | 10次三分钟Demo、30分钟热测试通过 | 回退最近稳定版本 |

### 16.3 当前必须等待实物的决策

- 雷达型号及 GPIO/UART 协议。
- TT 电机额定电压、减速比、堵转电流和实际负载能力。
- 电机驱动模块封装与散热能力。
- 电池化学体系、容量、保护板和连接器。
- OLED 驱动芯片和接口。
- 头部实际质量、力臂及舵机扭矩。

这些未决项不阻塞状态机、Mock、Agent、API和FreeCAD包络设计。

---

## 17. 未来演进

### 17.1 近期

- 将 PC ASR 替换为设备端已验证 KWS，或保留双后端。
- 增加边界/悬崖传感器后扩大移动范围。
- 在有明确功耗预算后加入更完整的电量计。

### 17.2 中期

- Insta360/摄像头接入独立 Vision Adapter；默认关闭，增加明显录制指示和物理隐私开关。
- 增加 SD 日记，但只保存结构化事件和用户明确授权的内容。
- 固件签名、受控 OTA 和恢复分区。

### 17.3 产品化前必须新增

- 儿童玩具机械、电气、电池和材料安全测试。
- 麦克风/摄像头隐私、数据删除和家长控制。
- 量产电源板、EMC/ESD、充电、跌落、夹手和小零件风险评审。
- 云端账户、设备身份、密钥轮换、成本与服务可用性设计。

---

## 附录 A：需求覆盖结论

- 完整功能需求分析共识别 36 项 P0、6 项 P1、9 项 P2，见 `../bmad/outputs/fr-analysis.md`；本文合并为 14 个能力组并分配到明确组件。
- 完整非功能需求分析共识别 43 项详细 NFR，见 `../bmad/outputs/nfr-analysis.md`；本文列出 19 个高优先级代表项及验证方式。
- 当前软件架构：可进入实现。
- 当前硬件 BOM：不可最终冻结，需通过 G0/G2 实物门禁。

## 附录 B：官方参考

- [ESP-Claw 官方仓库](https://github.com/espressif/esp-claw)
- [ESP-Claw v0.1.0 发布说明](https://github.com/espressif/esp-claw/releases/tag/v0.1.0)
- [ESP-IDF 6.0 idf.py 与官方 MCP](https://docs.espressif.com/projects/esp-idf/en/release-v6.0/esp32/api-guides/tools/idf-py.html)
- [ESP-SR WakeNet](https://docs.espressif.com/projects/esp-sr/en/latest/esp32s3/wake_word_engine/README.html)
- [ESP-SR MultiNet](https://docs.espressif.com/projects/esp-sr/en/latest/esp32s3/speech_command_recognition/README.html)
- [ESP-SR 资源占用基准](https://docs.espressif.com/projects/esp-sr/en/latest/esp32s3/benchmark/README.html)
- [ESP32-S3-WROOM-1 数据手册](https://documentation.espressif.com/esp32-s3-wroom-1_wroom-1u_datasheet_en.pdf)
- [TI DRV8833](https://www.ti.com/product/DRV8833)
- [Toshiba TB6612FNG](https://toshiba.semicon-storage.com/eu/semiconductor/product/motor-driver-ics/brushed-dc-motor-driver-ics/detail.TB6612FNG.html)

## 文档历史

| 版本 | 日期 | 变更 |
|---|---|---|
| 1.0 | 2026-08-31 | 首版系统架构；以移动机器人和后续确认决策覆盖PRD早期静止/PIR方案 |

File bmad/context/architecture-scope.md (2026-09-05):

# 牛来机器人架构需求基线

日期：2026-08-31  
状态：供架构分析使用，后续已确认决策优先于 IMA PRD v1.1 中的早期假设

## 1. 项目目标

在硬件黑客松中完成一只约 360 mm 高的自主移动硬壳牛形机器人。核心体验是双人格反差：

- 有人时：故意装成呆板机械牛；听到“牛来”后，用本地固定音频回答“妈妈”，配合眼睛、嘴和头部动作。
- 无人时：恢复“有灵魂”的人格，自言自语、轻度吐槽并在安全范围内自由移动。
- 一旦检测到人或人员状态不确定：立即中止私密话语和自由动作，切回机械人格。

目标是比赛现场稳定演示，不是产品量产版。

## 2. 团队与约束

- 团队：2 名计算机专业 + 1 名智能制造工程专业；机械设计经验偏弱。
- 打印设备：拓竹 A2L，成型空间 330 × 320 × 325 mm，机身必须分件打印。
- CAD：FreeCAD 可用。
- 外观生成：可用混元 3D 或群核科技生成 STL。
- 工期：黑客松短周期，必须允许硬件未到场时用 Mock、按钮和桌面模拟器开发。
- 现有项目目录尚无固件代码；当前只有概念图。

## 3. 已确认产品行为

### 3.1 人格状态

1. `MECHANICAL_PRESENT`：有人，机械人格。
2. `SOUL_ABSENT`：确认无人，本性人格。
3. `SAFE_UNKNOWN`：传感器未知、初始化、超时或故障；按“有人”处理并停止自由活动。
4. `EMERGENCY_STOP`：实体急停或严重故障；所有执行器进入安全状态。

### 3.2 硬安全约束

- 从收到“有人/未知”事件起，运动命令必须在 300 ms 内被取消并进入停车流程；传感器自身检测延迟另行记录。
- 安全优先级：实体急停 > 人员 PRESENT/UNKNOWN > 障碍 > 低电量 > 正常动作 > LLM 意图。
- LLM 和 Lua 只能调用白名单语义动作，不能直接输出 PWM、舵机角度、轮速或无限时长动作。
- 上电、重启、断网、Agent 超时、脚本崩溃和传感器故障均默认停车。
- “妈妈”固定音频必须本地可播，核心演示不依赖网络。

### 3.3 人格内容边界

- 无人吐槽允许轻度喜剧性用语，例如“蠢、烦死了、像没装脑子”。
- 禁止脏话、仇恨、受保护特征攻击和危险诱导。
- 保留“被迫喊妈妈次数”和“待吐槽内容”等轻量记忆。

## 4. 已确认机械方案

- 形态：全硬壳、直立拟人牛、低重心、矮胖比例。
- 目标外形包络：约 H360 × W220 × D180 mm。
- 底盘：隐藏式两驱轮 + 后部滚珠万向轮 + 前部防倾支点。
- 头部：水平转头 + 上下点头两轴；嘴巴独立开合一轴。
- 手臂：首版固定，保留未来安装孔。
- 眼睛：单块 2.42 寸 OLED，通过两个眼窗显示双眼。
- 扬声器：胸口独立音腔。
- 麦克风：一只耳朵内，远离扬声器和电机。
- 人体存在雷达：胸口或上腹非金属壳体后方。
- 超声波：隐藏为鼻孔，用于前方避障，不用于判断是否有人。
- 维护：背部检修门；电池位于下部并可拆；背部预留未来 Insta360 安装接口。
- 混元/群核输出只负责外观曲面；FreeCAD 参数化骨架负责承力、孔位、卡扣、螺丝柱、电机座、舵机座和分件接口。

## 5. 已知硬件与缺口

### 5.1 物料表中可用或可能可用

- ESP32-S3 N16R8。
- TT 马达。
- 2.42 寸 OLED（数量有限）。
- 4 Ω 扬声器。
- WS2812 灯带。
- 24 GHz 毫米波雷达，具体型号和接口尚未知。
- HC-SR04 超声波。
- MP1584EN 降压模块。
- SD 卡模块、按钮、面包板、杜邦线。
- 电池包条目存在，但电芯、保护、容量和接口未知。

### 5.2 需要自备或到货后确认

- 电机驱动：TB6612FNG / DRV8833 只是候选；最终按电机堵转电流选型。
- INMP441 I2S 麦克风。
- MAX98357A I2S 功放。
- 真正可定位的 180° 舵机；360°连续旋转舵机不能用于头部精确定位。
- 实体急停按钮、保险/过流保护、带保护电池/BMS/充电方案。
- 头部舵机扭矩型号；需根据实物头部质量和力臂决定。

### 5.3 主要不确定性

- 最终重量可能使 TT 马达扭矩不足；底盘必须支持换用更强减速电机。
- 毫米波型号、GPIO/UART 接口和区域配置未知；驱动必须抽象。
- 2.42 寸 OLED 的驱动芯片、接口和供货数量未确认。
- FreeCAD 当前没有从终端 PATH 验证到，但用户确认已安装，可能是自定义/便携路径。

## 6. 已确认软件技术方向

- 主控：ESP32-S3 N16R8。
- 固件基座：Espressif ESP-Claw `application/edge_agent`，从 `eda_robot_pro` 参考板派生 `niu_robot`。
- ESP-IDF：先锁定 ESP-Claw 当前已验证的 5.5.4 构建线和具体 Git commit；不为了官方 IDF 6 MCP 强行升级。
- 设备端模式：单固件、模块化单体 + 事件驱动状态机；不把 xiaozhi-esp32 和 ESP-Claw 两套完整固件直接合并。
- 安全层：C/C++ 编写，拥有运动、舵机和功率保护的最终裁决权。
- Agent 层：ESP-Claw 负责事件、人格、记忆、Capability、Lua 动作组合和可选云端调用。
- 云端：OpenAI 兼容 LLM，仅用于无人状态下的短句人格文本和高级语义意图；失败时使用本地语料库。
- TTS：比赛首版可用云端/PC TTS，但必须有本地固定语音和吐槽兜底。
- 唤醒词：本地 KWS 是待验证项；隐藏按钮必须映射到同一 `WAKE_NIULAI` 事件作为演示备份。
- `presence_read()` 返回 `PRESENT | ABSENT | UNKNOWN`；驱动可替换为 Mock、按钮、GPIO 雷达或 UART 雷达。

## 7. P0 功能范围

1. 两驱前进、后退、转向和停止。
2. 超声波避障与实体急停。
3. 人员 `PRESENT/ABSENT/UNKNOWN` 三态感知和人格切换。
4. “牛来”事件触发本地“妈妈”音频、嘴部开合、眼睛和头部动作。
5. 无人状态下安全的短距离自主游荡、转头、眨眼和吐槽。
6. 云端 LLM/TTS 不可用时自动使用本地语料，不破坏三分钟 Demo。
7. 结构可拆装、可维护、低重心且防倾倒。
8. 结构化日志至少记录状态切换、停车原因、传感器状态、电量和 Agent 超时。

## 8. 明确不在 P0

- Insta360 摄像头和视觉识别。
- 手臂、尾巴运动。
- 楼梯、室外、地毯和复杂地面导航。
- 小智与 ESP-Claw 双固件融合。
- LLM 直接控制电机、舵机角度或 PWM。
- 完整手机 App、量产 OTA、账户体系和云端大规模服务。
- 长期 SD 日记、照片记录和多用户身份识别。

## 9. 目标验收指标

- 连续完成完整三分钟 Demo 至少 10 次，无死机、撞击、倾倒和人格穿帮。
- `PRESENT/UNKNOWN` 事件到运动命令撤销不超过 300 ms。
- 上电、断网、传感器断开、Agent 卡死、低电和急停均进入确定性安全状态。
- 无网络时仍可完成：检测、人格切换、移动/停止、眼睛、头部、嘴巴和本地语音。
- 在最终重量假负载下完成底盘移动、急停和热测试，再安装正式外壳。

## 10. 来源优先级

1. 本文件中“已确认”的后续用户决策。
2. IMA《牛来机器人PRD-v1.1-2026-08-31.md》。
3. IMA《牛来机器人-技术开发决策记录-2026-08-31.md》。
4. 比赛物料表图片。

PRD 中以下早期内容已被覆盖：PIR 改为毫米波存在检测；静止桌面玩具改为移动底盘；旧物料编号映射无效；LLM/TTS 不再是离线核心演示的硬依赖。

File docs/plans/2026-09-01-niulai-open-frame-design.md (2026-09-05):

# 牛来机器人开架机电骨架设计 v0.1

## 目标

先建立可检查、可拆装、可参数化的机电骨架，再设计牛来外壳。首版必须在不依赖外壳承力的情况下，明确左右驱动、低位电池、电子层、PAN/TILT 头架和 MOUTH 嘴部机构的位置。

## 方案选择

采用“分层底盘 + 双立柱头架”。底层容纳两驱、滚珠万向轮、电池和防倾件；电子层用 M3 隔柱与动力层分开；两根颈柱直接连接底盘主板，顶部依次布置 PAN 平台、TILT U 型架和头部接口板。该方案比单立柱更容易用 FDM 打印和现场修补，也比一体式硬壳更适合器件未到齐时迭代。

## 参数化边界

整体目标包络为 H360×W220×D180 mm，单件必须适配 330×320×325 mm 打印空间。v0.1 暂用 TT 电机 68×23×18 mm、SG90 23×12.2×29 mm 和 64 mm 车轮占位；所有相关孔位和包络集中在生成脚本参数中。外观网格只连接头部接口板和底盘外壳孔，不承担电机、舵机或头部载荷。

## 验证门禁

生成时自动检查单件打印包络、整机目标包络以及六组不应相交的硬件碰撞；同时输出基于 PLA 体积和占位硬件质量的粗略重心。v0.1 只能通过数字布局门，不能通过打印冻结门。实物到货后必须完成接口试片、孔距复测、舵机限位、头部最坏姿态重心和最终重量假负载急停测试，才能发布 v0.2。

## 工程视图表达规范

经确认，v0.1 使用三张彼此独立的工程预览：整机骨架总览、底盘动力爆炸图和头部三执行器爆炸图。结构件必须为实体色，PAN、TILT、MOUTH 舵机分别使用蓝、紫、红三色；局部图必须完整入镜并说明未显示的部分。爆炸位移、虚线和运动轴只存在于渲染层，不写回 FreeCAD 几何。渲染器不得同时绘制 FreeCAD 组合对象及其子零件，避免重复网格、重影和错误的“第二套机构”观感。

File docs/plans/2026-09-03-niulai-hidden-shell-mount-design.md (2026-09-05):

# 牛来机器人隐藏式外壳安装与尺寸冗余设计 v0.5

## 结论

外观尺寸保持约 **宽 220 × 深 200 × 高 330 mm**，不通过整体放大解决装配问题。含车轮与防倾件的工程骨架包络为 **212 × 154 × 296.5 mm**；加入外壳安装座后的关键内部包络约为 **114 × 105 × 289 mm**。五片外壳分别打印，均适配拓竹 A2L 的成型空间。

## 已选方案

采用四个独立的隐藏式 M3 热熔螺母安装座，不采用连续椭圆环。连续环曾在数字复核中穿入 AI 生成外壳的不规则腿部/腹部，最近距离接近 0 mm，已淘汰。

四个安装点坐标为：

- 前左、前右：`(-50, -40)`、`(50, -40)` mm；
- 后左、后右：`(-45, 40)`、`(45, 40)` mm；
- 安装座直径 14 mm，高 8 mm，Z=72–80 mm；
- 底盘定位凸台直径 8.0 mm，安装座定位沉孔直径 8.4 mm；
- M3 热熔孔名义直径 4.2 mm，但必须先打印 4.0/4.2/4.4 mm 三档试片；
- 螺丝从底盘下方拧入，建议先备 M3×40 和垫片，再按实装缩短。

底盘立柱同时作为粘接治具：先把四个安装座套在定位凸台上并松装螺丝，再套上身体外壳，用环氧胶泥填充安装座与不规则内壁间的约 3–6 mm 间隙；固化后从底部松螺丝即可整体提壳。外壳仍为底部开放、可拆结构，不承受电机或头部主要载荷。

## 尺寸与安全冗余

- 静态电子件对外壳：门槛 5 mm；当前最小值为 ESP32 占位件约 5.63 mm。
- 运动件对外壳：门槛 8 mm；当前最小值为嘴部机构约 8.11 mm。这是最紧张位置，真实舵盘和连杆到货后必须复测。
- 承力结构对外壳：门槛 3 mm；当前最小值约 5.98 mm。
- 新增独立安装座：扣除 0.8 mm 网格离散误差后的保守间隙约 4.11 mm，门槛 1.5 mm。
- 新增底盘安装立柱：同口径保守间隙约 6.43 mm，门槛 1.5 mm。
- 电池设计包络仍为 100 × 60 × 30 mm，托盘净腔扩大为 104 × 64 mm，每侧留 2 mm，并保持开放绑带固定。
- ESP32、驱动、电源与未知 PCB 继续使用长圆孔/绑带，不冻结主办方未提供的孔距；USB、端子和线束应额外预留 10–15 mm 插拔与弯折空间。

## 验证证据

- FreeCAD 生成：19 个 STL，全部适配 A2L；装配包络通过 220 × 200 × 331 mm 设计边界。
- FreeCAD 实体检查：原有 6 组关键硬件碰撞为 0；新增安装立柱/安装座与 16 组邻近结构及硬件碰撞为 0。
- v0.4 高密度外壳网格近邻复核：安装座与立柱均通过保守间隙门禁。
- 旧连续安装环和旧预览网格已从生成目录清理，避免误打印。

## 首次打印顺序

1. 打印 `19_m3_heatset_coupon.stl`，使用最终耗材、喷嘴、层高和真实热熔螺母选择孔径。
2. 打印一个安装座或把四座低填充试打，套入 8.0 mm 定位凸台，确认 8.4 mm 沉孔不紧不晃。
3. 打印底盘并空装 TT 电机、电池假块和颈柱，确认线束方向。
4. 四个安装座使用底盘作治具粘入外壳；完全固化后再拆壳。
5. 真实舵机、舵盘、连杆、电池和主板到手后重新跑装配门禁，之后才能把整套标成“可整机打印冻结版”。

## 当前状态

这是黑客松 P0 的可制造候选，而不是量产冻结件。现阶段不建议继续放大整只牛；若实物复测仍失败，优先改可换托盘、安装座和舵机支架，只有外壳本身的连续干涉超过 5 mm 时才考虑整体放大 3%–5%。

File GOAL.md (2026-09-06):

# 牛来 overnight GOAL

日期：2026-09-06 凌晨 → **12:00 交卷**  
仓库：`23xxCh/ox-robot`  
工作区：`E:\AI WORK\硬件黑客松`  
固件树：`E:\XIAOZHI_NATIVE\xiaozhi-esp32`（overlay 同步 `firmware/xiaozhi-niulai/`）

## 北极星

一只桌上的潮玩牛：**人在时是礼貌玩具，人走后才过自己的生活。**  
观众不听解说也能看懂反差。技术服务于这场戏，不追求第二块板、官网云或完整 ESP-Claw。

## 已锁定（禁止回退）

后面任何 agent / 循环 / 提交都不能改掉这些：

1. **靠近不喊**：冻腿、打断 SECRET 吐槽、切断私有 WSS、只显示 **聆听** 脸。不播妈妈。
2. **喊「牛来」/ BOOT / KY-004**：先 `PlaySound(OGG_MAMA)` 约 2.2 秒，再礼貌听、想、说。走私有大脑。
3. **礼貌对话里让它动**：大脑可写白名单 Lua `niu.walk` / `niu.turn`（ttl≤2000），板端短促执行。靠近仍立刻冻腿。
4. **离开约 8 秒**：SECRET。不礼貌吐槽、其他表情（困/眨眼/思考/生气/吃惊）、短促晃腿。
5. **TFT**：全屏黄牛脸，棕色底。人在场只有聆听/微笑（说话时嘴动）。禁止再出现全白屏。
6. **私有 WSS only**：`ws://192.168.10.95:8000/xiaozhi/v1/`。拒绝 `xiaozhi.me`。不合完整 ESP-Claw。舵机 5V 外供。GPIO 12 是 CHRG，左后舵机 GPIO 9。
7. **冻结走板端 C**，不走 LLM。

## 完整系统 = 本轮 P0（今晚必须做完）

「完整」指 **12:00 能连拍 3 分钟真机戏** 的软件闭环，不是 v2 SPEC 里的全部场景引擎。

| ID | 交付 | 完成标准 |
|---|---|---|
| P0-1 | 生命循环 | PRESENT 冻 / 唤醒妈妈+礼貌 / ABSENT 吐槽+晃。测例覆盖状态转移。 |
| P0-2 | 黄牛脸 | SetupUI 之后画脸。人在：listening / happy。人走：secret 表情。说话嘴动。 |
| P0-3 | 礼貌说话 | 私有 WSS ASR→LLM→TTS。礼貌口吻。让动才发 Lua。 |
| P0-4 | 记忆进台词 | `MemoryStore` 接到真机路径：妈妈次数、上次被打断的事、最近 5 句不重复。独处会翻旧账。 |
| P0-5 | 独处生活 | 不只 11 秒一句。有冷却、换话题、可安静。断链时播本地 `secret*.ogg`，不假称云端在聊。 |
| P0-6 | 动作 | PRESENT 仅 Lua 短促走/转；ABSENT 可随机晃；任何靠近立刻 1500 µs。ttl≤2000。 |
| P0-7 | 大脑进程 | `0.0.0.0:8000` 健康。改 `brain/` 后优雅重启 uvicorn，不丢端口。WLAN 仍是 192.168.10.95。 |
| P0-8 | 测试与仓库 | `python -m pytest` 全绿。overlay 与 native 板型目录同步。推 `23xxCh/ox-robot`。 |
| P0-9 | 交卷材料 | Submission / Checkpoint2 / README / 飞书附录与真机行为一致。不写没做的能力。 |
| P0-10 | 微信 ClawBot | 用 iLink/OpenClaw 接到用户已有的微信 ClawBot。微信消息走同一意图管道。人在场只礼貌回、不泄密、不远程走腿；人走开才可吐槽+短促走。无 token 时测例绿、只进发件箱，不假装已连上真微信。 |

## 不做（P1 / 禁止假装完成）

- 外壳总装、真正四足步态闭环、第二块板、毫米波、六轴
- 打开 xiaozhi.me / 官方 OTA / 合入完整 ESP-Claw
- IM **绕过冻结** 远程走腿（人在场时微信不能驱动腿）
- 完整 SPEC 场景 JSON 播放器、向量检索、微服务
- **不要闪 COM6**，除非：(a) 大脑挂了且必须改固件 URL，或 (b) WLAN IP 变了，或 (c) 屏又全白。闪之前在回复里写原因。默认只改源码 + 本地编译。
- 不要删 `NiulaiStartPoliteChat` 里的妈妈。不要把 PRESENT 无唤醒改回自动走路。

## 人才能做（循环不要假装）

- ≤3 分钟连续录像：妈妈 → 礼貌聊 → 靠近冻 → 离开 8 秒吐槽+表情
- 把 `docs/feishu-checkpoint2-append.xml` 贴进飞书
- 接线、外供 5V、机械装配
- 微信里打开 ClawBot 插件并扫码；把 `NIULAI_CLAWBOT_TOKEN`（以及可选 `NIULAI_CLAWBOT_BASE_URL`）写进本机环境。没有 token 循环不得声称「微信已连通」

循环每次只在进度里提醒这两项还没拍/没贴，不要把时间花在写新文档催人。

## 通宵怎么跑

每 20 分钟一个 sprint：

1. 读本文件 + 当前 `firmware/xiaozhi-niulai/` + `brain/app/main.py` + `application.cc` 的妈妈函数。
2. 选 **一个未勾选的 P0**，做最小可验证改动。
3. 跑相关测例；`python -m pytest` 要绿。
4. 同步 overlay → `xiaozhi-esp32/main/boards/niulai-s3-expand-v17/`。
5. 提交并 `git push`（不要 force）。
6. 大脑若改了 Python：只重启 **自己拉起的** uvicorn；现役 PID 若 `/health` 已 ok 且代码已加载就不要再抢 8000。
7. 笔记本保活。不要让电脑睡觉。
8. **12:00 中国时区之后停止开发**，只做健康检查，并 `scheduler_delete` 本循环。

## 进度（循环每完成一项把 `[ ]` 改成 `[x]` 并写一行证据）

- [x] P0-2 黄牛脸源码 + 已烧 COM6（2026-09-06 凌晨，SetupUI 后画脸）
- [x] 妈妈先播再礼貌（`PlaySound(OGG_MAMA)+2.2s` 仍在 `application.cc`）
- [x] P0-4 记忆接到 WSS 说话路径（wake 计妈妈次数；PRESENT/abort 记下打断；ABSENT 翻旧账且最近 5 句去重。测例 `test_wake_counts_mama_and_absent_uses_interrupt`）
- [x] P0-5 独处冷却 / 不重复 / 断链本地 secret ogg（SecretDirector：≥11s 冷却、每 3 拍可安静、最近 5 句去重；WSS 失败轮播 secret1/2/3.ogg。测例 `test_director_cools_down_allows_quiet_and_rotates_local_clips`）
- [x] P0-6 PRESENT Lua 走路源码已有，测例+文档对齐；默认不烧板（`test_present_walk_sends_motion_with_ttl_cap` + freeze 负例 + `niu.walk` ttl≤2000；firmware README 已写礼貌短走。硬件未烧）
- [x] P0-3/P0-7 礼貌对话回归测例 + `/health` 可识别版本（`test_hello_listen_roundtrip` / `test_present_wake_is_polite_not_roast` / abort+ASR/TTS 失败恢复 / `test_health_version_is_not_placeholder_0_1_0`；`pytest brain/tests` 97 passed。现役 8000 未重启，现场 GET 仍仅 `status=ok`）
- [x] P0-8 pytest 全绿并 push（63 passed，`d79fe06`）
- [ ] P0-9 交卷稿与锁定行为一致
- [x] P0-10 微信 ClawBot 适配器：`POST /im/clawbot/event`（iLink item_list + OpenClaw hook），无 token 只进发件箱；冻结不走腿。测例在 `test_im.py`。真微信仍差人扫码/`NIULAI_CLAWBOT_TOKEN`
- [ ] 人：录像
- [ ] 人：飞书粘贴
- [ ] 人：ClawBot 扫码 / 填 token

## 持续产品迭代入口（2026-09-06 新请求）

用户新增要求：Grok持续迭代，并兼任产品经理设计功能、按固定标准提高整体评分。下一轮先读 [GROK_LOOP.md](GROK_LOOP.md)、[产品功能队列](.grok-loop/PRODUCT_BACKLOG.md) 与 [评分合同](.grok-loop/SCORECARD.md)，核对现有唯一循环后接管。

本入口不改写以上锁定人格、接线和现役行为。12:00交卷版本仍冻结；截止后的持续改进进入隔离工作区，不自动更新样机。每3轮做一次产品优先级与独立评分复评，目标整体80分、各维至少60、生命体验/嵌入式/安全至少80，分数只随证据增长。文件写入不代表调度器已启动，首次接管需记录实际任务ID和单写者状态。

## 快速完成调度覆盖（2026-09-06）

用户要求提速。下一轮先执行 [.grok-loop/FAST_TRACK.md](.grok-loop/FAST_TRACK.md)：复用现有总控，最多3个开发子代理分管后端语音、固件、角色记忆；当前L02原写者保持文件所有权，同一文件只由一个人修改。完成即交，不等20分钟；分线针对性测试、总控统一集成回归。先完成核心演示内部联调，再推进整体80分目标，不降低安全和证据要求。状态文件由当前Grok总控维护，本次文档更新没有代为启动子代理。

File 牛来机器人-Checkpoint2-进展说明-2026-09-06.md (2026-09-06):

# 牛来机器人 · Checkpoint 2 进展说明

| 项 | 内容 |
|---|---|
| 项目名称 | 牛来（潮玩生命玩具 / ox-robot） |
| 日期 | 2026-09-06 |
| 节点 | Checkpoint 2 = 9.6 10:00–10:30；Submission = 9.6 12:00 |
| 交卷文件 | [牛来机器人-Submission-2026-09-06.md](./牛来机器人-Submission-2026-09-06.md) |
| 代码仓库 | https://github.com/23xxCh/ox-robot |
| 飞书提交稿 | https://my.feishu.cn/wiki/Afn3w2nH8iuzd6kMbcEc0NY8nBf |
| 团队 | 陈熙贤（硬件）· 潘炜德（软件）· 微微（产品 & 商业） |

一句话：有人靠近时它先停着等人喊；喊「牛来」先播电影「妈妈」，再礼貌听、想、说。人离开约 8 秒后，才用笔记本私有大脑自己吐槽。冻结走板端 C，不连小智云。

---

## 1. 相对 Checkpoint 1，新完成的部分

### 1.1 板端生命循环（本轮核心）

- 板型 `niulai-s3-expand-v17` 已烧进 COM6。喇叭音量 90。靠近立刻冻腿、`ResetDecoder()`、打断吐槽。不连 xiaozhi.me。
- 超声 GPIO8/17：近距（约 55 cm 内）**立刻**四腿 1500 µs 中位。不把超时当成「确认无人」。
- 约 8 秒没有近距才进入 SECRET：随机步态小晃。笔记本 `brain/` 必须在私有 `ws://192.168.10.95:8000/xiaozhi/v1/`（当前 WLAN）。吐槽是 LLM + 千问 `qwen3-tts-flash` Dylan，约 11 秒一句。再靠近立刻停腿、切断通道、等人喊。不连 xiaozhi.me。
- 屏上是黄牛来脸。喊单次「牛来」/ KY-004 / BOOT：先播电影「妈妈」约 2.2 秒，再礼貌听、想、说，走私有大脑，跳过官方 OTA。有人时脸只用听/笑；礼貌对话里让它动可短促走/转（ttl≤2000）。靠近仍冻腿。

### 1.2 本地大脑（笔记本，本轮不假装已接通真机 TTS）

- FastAPI `brain/`：人格 MECHANICAL/SECRET、Lua `niu.*`、MCP `ttl_ms ≤ 2000`、飞书/微信 `event_id` 去重、SQLite、排练页、公开 `/life` 人设页。
- `/life` 可在笔记本上写人设、用 DashScope Qwen 兼容模式对话。这不是小智云，也不驱动真机冻结/舵机。无 key 时测例仍绿。
- 真机 SECRET 走私有 WSS 到笔记本 brain（DashScope `qwen3-tts-flash` Dylan）。这不是小智云。笔记本没开或 IP 变了，独处就没声音。路演不把 `/life` 当成真机在聊。

### 1.3 机械与接线

- 打印包仍是 v0.5。现场用开框/面包板能站上桌即可。
- 灯 S=GPIO14，键 S=GPIO18。屏 SCL=21、MOSI=47，不能再占。左后舵机 **GPIO 9**；GPIO 12 是板上充电指示 CHRG，PWM 会打架。

---

## 2. 还剩什么（到 12:00 交卷）

| 序号 | 事项 | 是否阻塞 90 秒演示 | 说明 |
|---|---|---|---|
| 1 | ≤3 分钟连续真机录像 | 交卷需要，路演可现场演 | 拍：喊「牛来」先「妈妈」再礼貌对话 + 靠近冻住打断吐槽 + 离开 8 秒后晃并自己说话 |
| 2 | 外壳总装 / 真正走路闭环 | 不阻塞 | 不演跑步 |
| 3 | 笔记本 brain 必须开着 | 阻塞独处说话 | WLAN 现为 `192.168.10.95`；IP 变了要改固件 URL |
| 4 | 灯绿/蓝、毫米波、第二块板 | 不阻塞 | 领了但本轮不用 |

不做什么：不合完整 ESP-Claw+小智；不用 ESP 的 5V 喂舵机；freeze 不交给大模型；不打开 xiaozhi.me 升级。

---

## 3. 新遇到的难点

1. **官方 OTA 会覆盖拦截。** 配过小智云后，官网 websocket/OTA 会把私有大脑冲掉。现固件启动跳过 OTA、拒绝打开官方音频通道。不要再进 xiaozhi.me 点升级。
2. **屏脚被占。** GPIO 21/47 是 ST7789 SPI。灯/键必须 14/18。
3. **舵机种类外观一样，且 GPIO 12 是充电指示。** 没给 1.5 ms 中位时，360° 会一直转。现固件 10/11/**9**/13 保持中位；SECRET 随机步态晃约 800 ms 再停。黄线接 12 会跟 CHRG 打架。
4. **HC-SR04 ECHO 是 5V。** ESP32-S3 GPIO 不耐受 5V。现场若 ECHO 直连，建议 1k+2k 分压；固件把超时当「没有近距」，不当成身份识别。
5. **虚拟 `SetupUI` 不会派发到子类。** 牛脸在 `NiulaiLcdDisplay` 构造函数里、基类 UI 建完之后再画，否则屏上仍是小智图标。
6. **Vorbis 的 ogg 喇叭无声。** 小智 `PlaySound` 只吃和官方铃声同款的 Opus。`mama.ogg` / `hi.ogg` / `secret*.ogg` 已转成 48 kHz Opus。

---

## 4. Checkpoint 2 巡场 60–90 秒

1. 指黄牛脸：「靠近时先停着，等人喊它。」
2. 喊「牛来」或按键 → 先听到电影「妈妈」，再礼貌听、想、说。说明：走私有大脑，不经小智云。
3. 手靠近超声，先别喊 → 腿立刻停，吐槽打断。
4. 手拿开等约 8 秒 → 腿随机小晃，约 11 秒一句吐槽。再靠近立刻停。
5. 打开仓库。不演 /life 闲聊，不演跑步，不连小智云。

---

## 5. 分工

| 人 | Checkpoint 1 | Checkpoint 2 / 交卷 |
|---|---|---|
| 陈熙贤 | 接线、供电、舵机外供 5V、超声、开框 | 现场确认灯 14 / 键 18、拍 3 分钟录像、外壳尽量站上桌 |
| 潘炜德 | 板型 overlay、本地妈妈、brain 测例 | 生命循环固件、拒绝小智云、Submission 文档、仓库 |
| 微微 | 飞书叙事、场景与商业 | 交卷清单、路演词、诚信声明 |

Checkpoint 加权仍是：进展 40% · 技术可行性 20% · 问题与场景清晰度 20% · 基础安排/分工 20%。

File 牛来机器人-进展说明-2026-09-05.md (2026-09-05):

# 牛来机器人 · Checkpoint 1 进展说明

| 项 | 内容 |
|---|---|
| 项目名称 | 牛来（潮玩生命玩具 / ox-robot） |
| 日期 | 2026-09-05 |
| 节点 | Checkpoint 1 已过；Checkpoint 2 = 9.6 10:00–10:30；Submission = 9.6 12:00 |
| Checkpoint 2 | [牛来机器人-Checkpoint2-进展说明-2026-09-06.md](./牛来机器人-Checkpoint2-进展说明-2026-09-06.md) |
| 交卷文件 | [牛来机器人-Submission-2026-09-06.md](./牛来机器人-Submission-2026-09-06.md) |
| 代码仓库 | https://github.com/23xxCh/ox-robot |
| 飞书提交稿 | https://my.feishu.cn/wiki/Afn3w2nH8iuzd6kMbcEc0NY8nBf |
| 团队 | 陈熙贤（硬件）· 潘炜德（软件）· 微微（产品 & 商业） |

一句话：人前它是一只只会说「妈妈」的机械玩具；人离开后，它才过自己的生活。本轮用**一块**小智 S3 扩展板 + 笔记本本地大脑做真机，不合完整 ESP-Claw 固件。

---

## 1. 已完成的部分

### 1.1 产品与叙事

- 场景与商业模式、创意创新、安全隐私、用户价值已写入飞书提交稿。
- 角色定案：喊「牛来牛来」只回答本地「妈妈」；公开场合不复活成聊天机器人。
- 无摄像头。近距用超声，不当成「人已离开」的铁证。

### 1.2 架构（已锁，不再改双板）

| 层 | 做法 |
|---|---|
| 身体 | 小智 S3 扩展板 V1.7 一块：屏、麦、喇叭、灯、键、超声、四路舵机信号 |
| 嘴 | 板端自定义唤醒 + 本地 `mama.ogg`，不打开云端对话 |
| 脑 | 笔记本 FastAPI brain：人格、记忆、MCP 白名单、飞书/微信入口 |
| 安全 | 冻结走板端 C，不走 LLM。舵机 5V 外供。继电器放弃 |

### 1.3 机械

- 开框 / BOM 兼容件 / 外壳接口做到 v0.5，打印包装在 `outputs/牛来机器人-A2L打印包-v0.5/`。

### 1.4 硬件接线（现场）

| 功能 | GPIO / 说明 | 状态 |
|---|---|---|
| 屏 ST7789 2" | SCL 21 · MOSI 47 · RST 45 · DC 40 · CS 41 · BL 42 | 板载，已点亮过 |
| 喇叭 MAX98357 | BCLK 15 · LRC 16 · DIN 7 | 板载 |
| 麦 I2S | WS 4 · SCK 5 · DIN 6 | 板载 |
| 超声 HC-SR04 | TRIG 8 · ECHO 17 | 已接线，固件预留 |
| 舵机 SG90 ×4 | 10 / 11 / **9** / 13，**5V 必须外供** | 左后不要接 12（充电指示 CHRG） |
| KY-016 灯 S | **改接到 GPIO 14**（不能占 21） | 三针模块本轮只会红 |
| KY-004 键 S | **改接到 GPIO 18**（不能占 47） | 按下为低，播本地妈妈 |
| BOOT | 0 | 短按切换聆听 |

GPIO 21 / 47 是屏的 SPI，灯和键接上去会花屏。

### 1.5 固件

- 板型 `niulai-s3-expand-v17`（小智 v2.4.2 overlay）已编译，烧过 COM6。
- 唤醒词：拼音 `niu lai niu lai` / 显示「牛来牛来」/ Multinet5。
- 唤醒后只播本地 `mama.ogg`，**不连云端对话**。
- KY-004 短按同样只播「妈妈」。
- 四路舵机上电保持 1.5 ms 中位（180° 停中间；360° 连续转会停）。
- 超声生命循环：近距立刻冻腿并说「你回来啦」；约 8 秒无近距才 SECRET 随机小晃约 800 ms，再停约 2 s，并播本地吐槽。屏上是牛来脸，不是小智图标。2026-09-05 19:06 已再烧 COM6（左后 GPIO 9）。

### 1.6 本地大脑

- FastAPI modular-monolith：生命周期人格、Lua 沙箱（只暴露 `niu.*`）、MCP ttl 帽、飞书/微信 webhook 去重、SQLite 记忆、网页排练。
- 协议测例已绿。仓库路径：`brain/`。

---

## 2. 剩余待完成的部分及计划

到 **9.6 10:00–10:30 Checkpoint 2**，再 **12:00 Submission**。

| 序号 | 事项 | 目标 | 截止 |
|---|---|---|---|
| 1 | 灯 S→GPIO14，键 S→GPIO18 | 屏正常 + 键播妈妈 + 喊「牛来牛来」播妈妈 | 今晚巡场前 |
| 2 | 确认一直转的那只舵机 | 黄线在 10/11/**9**/13，不要接 12（CHRG）；外供 5V；中位固件烧完后应停 | 已改线并再烧 COM6 |
| 3 | 超声近距 = PRESENT | 板端已做：近距立刻冻，8 秒无近距才 SECRET | 已合进固件 |
| 4 | 四足走/停/转头 | 本轮只演示可打断的对角小晃，不演跑步 | 路演不演走 |
| 5 | 开框或外壳上桌 | 能站着演示，不拖线一团 | Submission 前 |
| 6 | 选手手册 Part 5 全套 | 诚信声明 + 自选附件；≤3 分钟录像现场拍 | 9.6 12:00 |

不做什么：不合完整 ESP-Claw+小智；不用 ESP 的 5V 喂舵机；freeze 不交给大模型。

---

## 3. 遇到的技术难点

1. **屏脚被占。** GPIO 21 = SCL，GPIO 47 = MOSI。灯接 21、键接 47 会直接花屏。已改到 14 / 18。
2. **不能双固件硬并。** ESP-Claw 与小智是两套运行时，分区和内存过不去。语音留在小智 WSS，人格和动作放笔记本 brain。
3. **舵机电源与种类。** ESP 5V 带不动四路 SG90，必须外供。物料里 180° / 360° 外观一样：没给 1.5 ms 中位时，360° 会一直转。现固件对 10–13 做中位保持。
4. **三针 KY-016 只有一路 PWM**，本轮只会红。要黄/紫/白需要再引出绿、蓝。
5. **现场工具和备份件不足**，压缩了焊接和换件窗口。

---

## 4. 巡场 30 秒演示（今晚）

1. 屏能亮。
2. 按 KY-004 → 喇叭说「妈妈」。
3. 喊「牛来牛来」→ 同样只说「妈妈」，不开始闲聊。
4. 四只舵机停在中位，不空转。
5. 打开仓库链接，指出 `firmware/xiaozhi-niulai/` 和 `brain/`。

---

## 5. 赛制备忘

| 节点 | 时间 | 提交 |
|---|---|---|
| Checkpoint 1 | 9.5 17:00–18:00 | 本说明 + 代码仓（强烈建议） |
| Checkpoint 2 | 9.6 10:00–10:30 | 新完成 / 还剩什么 / 新难点 |
| Submission | 9.6 12:00 | 手册 Part 5 全套 |

Checkpoint 加权：进展 40% · 技术可行性 20% · 问题与场景清晰度 20% · 基础安排/分工 20%。54 队两次加权，Anchor 前 15 / Weave 前 20 进路演。

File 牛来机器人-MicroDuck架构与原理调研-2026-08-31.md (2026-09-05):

# 牛来机器人参考调研：MicroDuck 的架构与工作原理

> 调研日期：2026-08-31  
> 调研对象：Pollen Robotics / Hugging Face MicroDuck  
> 结论来源：官方产品页、官方运行时仓库、官方强化学习仓库及其架构设计文档。

## 1. 一句话结论

MicroDuck 不是“ESP32 玩具接一个大模型”，而是一台约 25 cm、800 g 的 Linux 双足机器人：Rockchip RK3566 单板机在机身内运行 Rust 服务，使用 50 Hz 控制循环读取 15 个智能舵机和 IMU，将 61 维机器人状态送入 ONNX 神经网络策略，再把 14 维动作转换成关节目标并经过安全层写回舵机。

它真正值得牛来借鉴的不是“双足强化学习”本身，而是四条工程原则：

1. 上层只提交“意图”，不能直接写电机。
2. 安全层独占执行器写权限。
3. 行为策略可以替换，传感器、控制周期和安全合同保持稳定。
4. 先在数字孪生中训练/测试，再部署到真机，并保留回滚能力。

## 2. 产品和硬件概况

官方公开的整机信息：

| 项目 | MicroDuck |
|---|---|
| 形态 | 小型双足鸭形机器人 |
| 高度/重量 | 约 25 cm / 800 g |
| 主计算 | Rockchip RK3566 Linux 单板机，当前软件针对 Radxa 平台 |
| 执行器 | 15 个 Dynamixel 智能舵机 |
| 策略控制自由度 | 14 个；嘴部舵机不进入运动策略 |
| 传感 | 摄像头、头部 8×8 ToF/LiDAR、双 IMU、舵机位置/速度/电流/电压/温度 |
| 音频 | 板载麦克风、扬声器和音频编解码器 |
| 电池 | NP-F550 形态的 2S 锂电池；运行时按 6.6–8.2 V 可用区间估算电量 |
| 通信 | Wi-Fi、蓝牙、USB/SSH、手柄、WebRTC |
| 控制频率 | 50 Hz，即每 20 ms 一次控制周期 |

### 2.1 关节布局

```text
左腿 5：髋偏航、髋横滚、髋俯仰、膝、踝
头部 5：颈俯仰、头俯仰、头偏航、头横滚、嘴
右腿 5：髋偏航、髋横滚、髋俯仰、膝、踝
```

15 个舵机和 `imu_to_dxl` 板共享一条 UART，使用 Dynamixel Protocol 2.0、1 Mbps。IMU 板使用单独设备 ID，但与舵机在同一批次读取。

## 3. 整体软件架构

MicroDuck 采用“单板多守护进程 + 单一实时控制核心”的模块化架构，而不是 ROS 2。

```text
       手柄           手机/BLE         浏览器/远程          CLI/SSH
        │                 │                │                  │
      padd               btd            mediad            robotctl
        └─────────────── 高层意图 / JSON-RPC ────────────────┘
                                  │
                         Unix Domain Sockets
                                  │
                    ┌─────────────▼─────────────┐
                    │ robotd：唯一运动控制核心 │
                    │ 50 Hz + 策略 + 安全层     │
                    └─────────────┬─────────────┘
                                  │ Dynamixel UART
                        15 舵机 + IMU 转接板

 configd：Wi-Fi、身份、配对、电源
 updaterd：签名更新、健康门禁、自动回滚
 tofd：8×8 ToF 深度流
 mediad：摄像头/麦克风、WebRTC、视觉推理
 btd：蓝牙传输适配
 padd：手柄输入适配
```

### 3.1 为什么拆成多个进程

- `robotd` 只负责运动控制、安全、策略和机器人状态。
- 摄像头、媒体和视觉推理崩溃，不能拖死电机控制。
- 即使 `robotd` 起不来，`configd`、`updaterd` 和 `btd` 仍能联网、重新配置或回滚。
- 每一类状态只有一个写入者，避免多个服务同时控制同一硬件。

### 3.2 进程通信

- 控制面：JSON-RPC 2.0 + NDJSON，运行在 Unix Socket 上。
- 数据面：摄像头/音频不塞进 JSON-RPC，单独走媒体管线和 WebRTC。
- 控制循环不做同步远程调用，跨服务数据采用缓存/最后值优先，防止阻塞 20 ms 周期。
- 手机、手柄、浏览器和 CLI 最终都发送同一套“意图”，不会各自拥有一条电机控制后门。

## 4. 最核心的工作原理：50 Hz 神经网络控制环

每 20 ms 执行一次：

```text
1. sync_read
   读取 IMU + 15舵机位置/速度/电流等
          │
          ▼
2. 构造 61维 Observation
          │
          ▼
3. 根据高层意图选择 ONNX Policy
   walk / stand / sit / kick / ground-pick / roulade...
          │
          ▼
4. ONNX 推理输出 14维 Action
          │
          ▼
5. 动作缩放 + 低通滤波 + 回填到15关节
   嘴部不受策略控制
          │
          ▼
6. Safety.apply
   NaN拒绝、关节限位、失联停车、跌倒处理
          │
          ▼
7. sync_write
   一次性写入全部目标关节角
```

### 4.1 61 维输入是什么

| 范围 | 数量 | 内容 |
|---|---:|---|
| 0–2 | 3 | IMU 角速度 |
| 3–5 | 3 | 机身坐标系重力方向 |
| 6–19 | 14 | 关节位置减去默认站立姿态 |
| 20–33 | 14 | 关节速度 |
| 34–47 | 14 | 上一时刻策略动作 |
| 48–60 | 13 | 速度、头部姿态和身体姿态命令 |

合计 `3 + 3 + 14 + 14 + 14 + 13 = 61`。

### 4.2 14 维输出是什么

神经网络输出14个连续值，对应左右腿和颈/头关节。运行时把它们乘以动作比例、叠加默认姿态，再经过低通滤波生成目标角度。第15个嘴部舵机被明确排除，因此嘴巴可以由声音/表情逻辑独立控制。

### 4.3 为什么不是直接让大模型控制舵机

LLM 反应慢、输出时间不确定，也无法稳定满足 20 ms 控制周期。MicroDuck 的客户端只能发送：

- 前进速度、横向速度、转向速度；
- 头部朝向；
- 站立、坐下、踢球、翻滚等技能意图。

`robotd` 再选择经过训练和验证的策略。这个模式与牛来设计中的 `Action Gateway + Safety Supervisor` 是同一种安全思想。

## 5. 强化学习和 Sim-to-Real 原理

MicroDuck 的走路不是人工编写每条腿的轨迹，而是在仿真中学习出来的。

```text
Onshape/CAD
    ↓ 导出 MJCF
MuJoCo Warp / mjlab 物理仿真
    ↓ 4096个并行环境
PPO 强化学习
    ↓ PyTorch checkpoint
导出 ONNX（包含 Observation Normalizer）
    ↓
真机 robotd / ONNX Runtime / 50 Hz
```

### 5.1 策略怎么学会走路

训练程序随机给机器人目标速度，奖励包括速度跟踪、站稳、姿态、能耗和动作平滑等；摔倒、动作突变或偏离目标则受到惩罚。PPO 不断更新神经网络，使累计奖励提高。

官方仓库给出的参考量级是：4096 个并行仿真环境训练可用步态约需 1–2 小时，前提是有 CUDA GPU。

### 5.2 为什么仿真里学会，真机也能走

关键不是单纯“加随机噪声”，而是针对真实执行器建模：

- 使用 BAM 的 Dynamixel XL330/M6 电机模型；
- 模拟反电动势、摩擦、负载相关摩擦；
- 随机化电池电压和负载压降；
- 随机化命令延迟；
- 随机化重心、质量和接触条件；
- 额外建立每个舵机约 ±1° 齿轮间隙版本；
- 训练和运行保持相同的动作缩放、低通滤波和 61维输入布局。

换句话说，Sim-to-Real 的核心是让仿真“像一批略有差异的真机器人”，而不是让策略只适应一个完美模型。

### 5.3 多策略切换

走路、站立、坐下、踢球、捡东西、前滚翻和轮滑不是一个万能模型，而是多个相同输入/输出合同的 ONNX 策略。运行时根据意图和优先级切换策略；因为接口统一为 `61 → 14`，切换时不用改控制总线。

## 6. 安全架构

MicroDuck 最重要的安全措施不是某一个传感器，而是“唯一写权限”。

### 6.1 执行器单一所有者

`Safety` 对象持有唯一的 `RobotIo`，策略、控制器和网络客户端只能提出目标。Rust 所有权/借用机制在编译期阻止其他模块直接写舵机，而不仅依靠团队约定。

### 6.2 运行时保护

- 非有限动作（NaN/Inf）直接拒绝，保持原姿态；不能简单 clamp 成一个看似合理的边界值。
- 超出关节范围的目标被截断，并在状态中报告原因。
- 速度意图超过约 500 ms 没刷新，速度归零，但机器人继续站立，不直接瘫软。
- 传感器读取失败时不伪造 Observation，也不继续让策略按旧状态驱动。
- 电池耗尽时先执行安全动作，再关机。
- 电机温度、电压、总线错误和控制周期均可观测。

### 6.3 跌倒处理

它有两个不同的判断：

1. “已经倒下”的姿态判定，用于报告状态；
2. “正在倒下”的预测器，根据陀螺仪与重力方向估计约 300 ms 后的姿态。

预测确认后，系统降低舵机刚度让机器人软着陆；检测到停止滚动后，把关节缓慢拉回已知姿态，再交给站起策略。这样避免机器人倒地后仍用高刚度反复挣扎。

## 7. 更新和恢复架构

- 整套服务按版本目录安装，不在当前版本上原地打补丁。
- 发布包经过签名验证。
- 切换 `current` 版本后重启服务并调用健康检查。
- 控制循环、总线或策略加载不健康时自动回滚到上一版。
- 单板配置和身份存放在发布目录之外，因此升级/回滚不会覆盖机器专属配置。

这套机制对黑客松 P0 太重，但“保留最后可工作的固件 + 每次改动跑完整演示回归”值得牛来直接采用。

## 8. 它现在有没有“大模型灵魂”

没有。官方当前主运行时的核心是运动策略、传感器、声音、媒体、联网、更新和遥控，并没有把 LLM 当作自主大脑。

官方规划中的自主行为栈尚未正式进入主守护进程。设计草案描述了16个状态：放松、环顾、游荡、原地转向、疯跑、受惊、伸展、整理羽毛、打喷嚏、跳舞、捡东西、睡觉、玩球、被抚摸、被抱起等；其选择由能量、情绪、新奇度地图、声音、ToF和社交输入共同决定。

所以要区分：

- MicroDuck 已经实现得很强的是“身体运动能力”；
- 规划中的状态机负责“像活物一样自主活动”；
- LLM/MCP 只是社区可扩展的高层入口，不是 50 Hz 身体控制器。

## 9. 对牛来机器人的可借鉴性

### 9.1 建议直接借鉴

| MicroDuck 做法 | 牛来对应实现 |
|---|---|
| 客户端发送 Intent | ESP-Claw/Lua 只发送语义 `ActionIntent` |
| `robotd` 独占电机 | `Safety Supervisor + Motion Controller` 独占 PWM/H桥 |
| Safety 持有唯一 RobotIo | HAL 电机写接口只对安全层私有可见 |
| 50 Hz 有界循环 | 牛来运动/安全任务固定周期，禁止网络阻塞 |
| Deadman | 动作租约到期自动停车 |
| FakeIo | 雷达、超声波、电机和舵机都提供 Mock |
| 统一 Observation/Action 合同 | 统一事件、状态快照和命名动作合同 |
| 多策略同接口切换 | 双人格状态机在同一动作集合上编排 |
| 仿真/实物一致参数 | FreeCAD 包络、质量、重心和动作限位进入测试基线 |
| 签名更新和回滚 | 黑客松阶段至少保存稳定固件、配置和回归结果 |

### 9.2 不建议照搬

1. **不照搬双足强化学习。** 牛来当前是差速轮移动，规则控制即可；引入 MuJoCo + PPO 会把机械、电机和训练风险同时放大。
2. **不照搬 Linux 七进程。** ESP32-S3 资源和系统模型不同，P0 使用 FreeRTOS 模块化单体更合适。
3. **不购买15个智能舵机来追求同样动作。** 成本、重量、供电和机械难度都会失控。
4. **不把 LLM 放进实时环。** LLM 负责台词与高层意图，安全与动作始终本地确定。
5. **不宣称 MicroDuck 的自主灵魂已经量产成熟。** 官方文档明确仍把 autonomous brain 作为后续工作。

## 10. 对牛来架构的实际调整建议

现有牛来“双平面架构”方向正确，不需要推翻：

```text
ESP-Claw / LLM / 人格状态机
           │ 语义动作
           ▼
Action Gateway
           │ 有时限的动作租约
           ▼
Safety Supervisor
           │
Motion / Servo / Audio / Display
```

受 MicroDuck 启发，建议补强四点：

1. 将电机/舵机唯一写权限落实到代码可见性，Agent、Lua和状态机都不能获得底层驱动句柄。
2. 建立固定 `RobotSnapshot`：presence、obstacle、battery、motion、servo_pose、faults、age。
3. 建立 `FakeRobotIo` 场景测试，在硬件到货前回放“突然有人、传感器失联、动作过期、低电、急停”。
4. 把“灵魂”实现成能量/情绪/新奇度驱动的本地状态机；LLM只为状态机生成候选台词，不负责决定电机 PWM。

## 11. 结论

MicroDuck 的核心竞争力可以概括为：

> 用高保真仿真和强化学习解决双足运动，用严格的软件边界和安全层把神经网络约束在可控范围内。

牛来不需要复制它昂贵、复杂的双足身体，但非常适合复制它的“上层意图—策略/状态机—安全层—唯一硬件写入口”结构。这会让牛来既能表现出自由人格，又不会因为 AI 输出或网络延迟失控。

## 12. 官方资料

- [MicroDuck 官方产品页](https://pollen-robotics.com/microduck)
- [MicroDuck 官方运行时仓库](https://github.com/pollen-robotics/microduck)
- [MicroDuck 系统架构](https://github.com/pollen-robotics/microduck/blob/main/docs/design/architecture.md)
- [`robotd` 50 Hz 控制架构](https://github.com/pollen-robotics/microduck/blob/main/docs/design/robotd-design.md)
- [运动模型与关节定义](https://github.com/pollen-robotics/microduck/blob/main/duck-control/src/model.rs)
- [61维 Observation 定义](https://github.com/pollen-robotics/microduck/blob/main/duck-control/src/obs.rs)
- [MicroDuck RL 官方仓库](https://github.com/pollen-robotics/microduck_rl)
- [自主行为栈草案](https://github.com/pollen-robotics/microduck/blob/main/docs/ideas/autonomous_behavior.md)

## 13. 调研边界

- 官方 `architecture.md` 和 `robotd-design.md` 当前标记为 draft，产品仍处于快速迭代期。
- 本文只把官方仓库和产品页作为确定性事实来源；社区复刻、MCP项目和第三方推测未用于硬件结论。
- 软件代码使用 Apache-2.0；强化学习仓库注明3D模型文件采用 CC BY-SA-NC，二次使用模型前需单独检查资产许可。

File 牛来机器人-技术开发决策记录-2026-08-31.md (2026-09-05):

# 牛来机器人：技术开发决策记录

> 日期：2026-08-31
> 项目：AIX ORIGIN 2026 首届深港联动黑客松 · Hardware 赛道
> 主控：ESP32-S3 N16R8（16MB Flash + 8MB PSRAM）
> 定位：双面 AI 陪伴玩具机器人（致敬《玩具总动员》+《牛来》）

---

## 一、项目概念（核心灵魂）

**双人格切换的 AI 陪伴玩具牛。**

| 状态 | 人格 | 说话 | 行为 |
|---|---|---|---|
| 人不在 | 本性活牛 | 吐槽 / 碎碎念 / 好奇 / 灵魂拷问（LLM 生成） | 转头环顾、东张西望、自言自语 |
| 人在 | 装傻机械牛 | 礼貌 / 机械 / 客套（固定话术） | 僵住、像普通玩具 |

**一句话定位（评委开场）**：主人面前，牛来是台死板的机器人；主人一走，它立刻卸下伪装，变成一只好奇心爆棚、到处吐槽的「活牛」。它不是不会说话，是**在主人面前假装不会**。

**灵感**：
- 《玩具总动员》——玩具只在被当朋友的主人面前活过来；主人不在有自己的生活
- 《牛来》——被取名「牛来」=「牛来了，要勇敢站起来」

---

## 二、功能需求

| 需求 | 功能 | 实现 |
|---|---|---|
| 感知 | 人在/人不在判断 | PIR 人体红外（主）+ 超声/红外辅助 |
| 对话 | 听懂 + 生成牛来的话 | LLM（人在用固定话术，人不在用 LLM 生成） |
| 动作 | 转头 / 点头 / 眨眼 | SG90 舵机 + OLED 屏 |
| 自主动作 | 人不在于自主行动，不是固定剧本 | 状态机 + 传感器驱动 + 随机化，或 LLM 决策 |
| 表达 | 发声 | 喇叭（TTS） |
| 记忆/身份 | 记住自己是谁、记得主人 | 本地记忆 / 会话存储 |
| 记录 | 它的一天 | SD 卡日记 / 摄像头照片 |

---

## 三、技术选型（gitsearch 调研后确定）

### 关键澄清：ESP-Claw 不是「服务在云端」

- **ESP-Claw 的 Agent Runtime（感知/决策/执行/Lua skill）= ESP32 本地**，官方将 Agent Runtime 下沉至边缘芯片
- **LLM 大模型推理 = 云端 API**（支持 OpenAI 风格 / Anthropic 风格 / 本地 LLM）
- **通信 = WiFi**，ESP32 联网调云端 LLM

### 最终架构

```
【ESP32 本地】ESP-Claw Agent Runtime
  ├ 感知（PIR/麦克风/传感器）
  ├ 决策 + 人格切换（双面，自研）
  ├ Lua skill 动作（舵机/OLED）
  ├ 本地记忆
  └ 连 LLM（WiFi）
        ↓ 调 OpenAI 兼容 API
【云端/PC】LLM（DeepSeek / Qwen 等）
```

---

## 四、候选基座对比（gitsearch 结论）

| 基座 | 维护状态 | 定位 | 决策 |
|---|---|---|---|
| **ESP-Claw** | ✅ 官方主推（⭐2.1k，08-28 更新） | 设备端 AI Agent 框架，LLM+Lua，自主动作/视觉 skill | ✅ **主基座** |
| **xiaozhi-esp32** | ✅ 成熟（⭐29.5k，08-30 更新） | 对话设备（ASR+LLM+TTS），MCP 多端控制 | ⚠️ 对话可借鉴/当 MCP |
| **MimiClaw** | ❌ 停更（v0.1，停顿 5 月） | $5 芯片 AI 助手，本地记忆 | ❌ 只借鉴思路，不基座 |
| **DeepSeek Harness** | ✅ 开源（本地已有） | Agent harness，一切皆插件 | 可选：当 OpenAI 兼容 LLM 端点 |

**关键结论**：
- 没人把「对话+自主动作」做成一体化的标准结合版 → **你的「双面人格」是差异化机会**
- MimiClaw 停更，别当基座
- DeepSeek Harness 本地已有，可当「可控/本地化模型端点」

---

## 五、架构取舍（曾纠结的点）

### 1. xiaozhi 对话 + ESP-Claw 动作 能拼吗？
- 两者都基于 **MCP 协议**，能协同
- 但都是「完整固件」，建议**选一个为主**，别双固件打架
- 48h 建议：ESP-Claw 为主（它自己能对话），动作逻辑自己实现

### 2. ESP-Claw 为主 + 小智对话做成 MCP？
- ✅ 可行且是社区标准做法（ESP-Claw 是 MCP client，能主动调任何 MCP server）
- 对话（ASR/LLM/TTS）可封装成 MCP server
- 有现成教程：「ESP32 + MCP over MQTT 情感陪伴智能体」（EMQX 系列）

### 3. DeepSeek Harness 能插吗？
- ESP-Claw 自己就能调 LLM 对话，所以 Harness **不是必需品**
- 只有当「本地化/可控模型」需要时才让它当 OpenAI 兼容端点

---

## 六、关键提醒（避坑）

1. **对话必须联网**：ESP-Claw 调云端 LLM，比赛现场没网就哑了
2. **ASR/TTS 是重负载**：ESP32 跑不动，放云端/PC
3. **MimiClaw 停更**：别当基座，出问题没人修
4. **48h 别过度设计**：简单对话 ESP-Claw 就够，别硬叠 DeepSeek Harness

---

## 七、比赛信息

- **AIX ORIGIN | 首届深港联动黑客松**（主办 InnoAIx）
- 时间：2026-08-31 至 09-06
- 地点：深圳华润前海（深港双城联动）
- 赛道：Hardware
- 物料表：主办方提供（ESP32-S3 核心板 N16R8、SG90 舵机、OLED、超声波、红外、喇叭、麦克风、SD 卡等）

---

## 八、数据来源

- gitsearch（多策略 GitHub 搜索）
- AnySearch 检索
- esp-claw / xiaozhi-esp32 / MimiClaw / DeepSeek Harness 官方仓库与文档

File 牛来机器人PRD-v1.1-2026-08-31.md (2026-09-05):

# 「牛来」双面AI陪伴玩具机器人 · 产品需求文档（PRD）

> 版本：v1.1
> 日期：2026-08-31
> 项目：AIX ORIGIN 2026 首届深港联动黑客松 · Hardware 赛道
> 主控：ESP32-S3 N16R8（16MB Flash + 8MB PSRAM，满足 ESP-Claw 要求）
> 技术基座：ESP-Claw（设备端 Agent）+ 云端 LLM
> 作者：参赛团队

---

## 1. 产品概述

**一句话定义**：
> 一只被主人取名「牛来」的 AI 陪伴玩具牛。**人离开时它回归本性（好奇、吐槽、碎碎念的活牛）；人出现时它瞬间切换成「故意装傻的机械牛」。** 致敬《玩具总动员》：玩具只在主人面前装成普通玩具，主人一走就偷偷活过来。

**核心价值**：不是一台「会说话的智能设备」，而是一个**有双重人格、会演戏、会偷偷活过来的「角色」**。

---

## 2. 灵感来源

| 来源 | 借鉴点 |
|---|---|
| 《玩具总动员》 | 玩具只在把主人当朋友时才有生命；主人面前装普通玩具，背后有自己的生活 |
| 《牛来》（2026 国产动画） | 萌系小牛形象；被取名「牛来」=「牛来了，要勇敢站起来」的成长内核 |

---

## 3. 目标用户 & 使用场景

- **对象**：儿童、独居者、喜欢潮玩/陪伴类智能硬件的人群
- **场景**：
  - 主人外出，牛来独自看家 → 露出本性
  - 主人回家 / 有人靠近 → 切换回机械玩具
  - 长时间独处 → 记录「它的一天」，对世界好奇

---

## 4. 核心概念：双人格切换（本项目灵魂）

| 状态 | 人格 | 说话方式 | 行为 | 是否用 LLM |
|---|---|---|---|---|
| **人不在** | 「本性活牛」 | 吐槽、碎碎念、好奇、灵魂拷问 | 转头环顾、东张西望、自言自语、晃动 | ✅ LLM 随机生成 |
| **人在** | 「装傻机械牛」 | 礼貌、机械、客套、重复应答 | 僵住、极僵硬、像普通玩具 | ❌ 固定话术 |

**一句话定位（评委开场）**：
> 主人面前，牛来是台死板的机器人；主人一走，它立刻卸下伪装，变成一只好奇心爆棚、到处吐槽的「活牛」。它不是不会说话，是**在主人面前假装不会**。

---

## 5. 功能需求

### 5.1 感知（人在不在判断）
| 需求 ID | 功能 | 说明 | 优先级 |
|---|---|---|---|
| F-01 | 人体存在检测 | 用 PIR（人体红外/热释电）检测是否有人在，作为「人格切换」的触发 | P0 |
| F-02 | 有人靠近辅助检测 | 超声波/红外避障辅助，减少误判（区分"人"与"宠物/空调"） | P1 |
| F-03 | 主人口令唤醒 | 麦克风识别关键词（如「牛来牛来」），实现"认主" | P1（可选加分） |

**触发逻辑**：
```
PIR 检测不到人 → 切换「本性活牛」人格
PIR 检测到人   → 切换「装傻机械牛」人格
```

### 5.2 双人格表达
| 需求 ID | 功能 | 说明 | 优先级 |
|---|---|---|---|
| F-10 | 本性人格：LLM 随机说话 | 根据「人设 + 当前情境」现场生成符合牛来性格的话 | P0 |
| F-11 | 机械人格：固定话术 | 刻意的机械、呆板、像智能音箱/客服的固定应答 | P0 |
| F-12 | 人格秒切换 | PIR 状态变化时，说话与行为立即切换，反差感强 | P0 |

### 5.3 运动（让它"活"起来）
| 需求 ID | 功能 | 说明 | 优先级 |
|---|---|---|---|
| F-20 | 转头环顾 | SG90 舵机，人不在时左右转、东张西望 | P0 |
| F-21 | 点头/摇头 | 舵机，表达情绪（人不在玩自嗨 / 机械应答时微动） | P1 |
| F-22 | 眨眼表情 | OLED 屏显示眼睛/表情动画 | P1 |
| F-23 | 感应转向看人 | 人靠近时，舵机转向人所在方位（进阶，可选） | P2 |

### 5.4 表达（发声）
| 需求 ID | 功能 | 说明 | 优先级 |
|---|---|---|---|
| F-30 | 语音播放 | 喇叭模块播放 TTS / 预设音频 | P0 |
| F-31 | 语音输入（可选） | 麦克风收录人的话，喂给 LLM | P2 |

### 5.5 记录（它的"一天"）
| 需求 ID | 功能 | 说明 | 优先级 |
|---|---|---|---|
| F-40 | 日记/日志记录 | SD 卡存储牛来独处时的所见所想（文字日志） | P1 |
| F-41 | 视觉记录 | 摄像头拍照（若清单有摄像头模块），存它"看到"的 | P2 |

---

## 6. 硬件需求（对照比赛物料表）

| 功能 | 部件 | 物料表编号 | 数量 |
|---|---|---|---|
| 主控 | ESP32-S3 核心板 N16R8 | 46 | 1 |
| 转头/点头 | SG90 舵机 | 50 | 2 |
| 眨眼/表情 | OLED 0.96 寸 / 1.3 寸 | 53 / 54 | 1 |
| 人在检测 | 人体感应 / 红外相关 | 6 / 7 / 12 确认 | 1-2 |
| 辅助检测 | 超声波模块 | 38 | 1 |
| 发声 | 喇叭模块 / 有源蜂鸣器 | 16 / 33 | 1 |
| 收音 | 麦克风 / 咪头 | 6 / 15 | 1 |
| 记录 | SD 卡模块 | 41 | 1 |
| 接线 | 杜邦线 / 面包板 | 49 / 48 | 若干 |
| 外观 | 牛公仔 / 3D 打印壳 | 自备 | 1 |

**⚠️ 待确认项**：
- 摄像头模块（物料表未见明确）——F-41 依赖，若无则仅做文字日记
- 电机+底盘（物料表未见明确）——若要牛来"走路"需确认；**建议本项目不走路，靠转头/点头/眨眼实现"活"**

---

## 7. 技术架构

### 7.1 架构澄清（关键）

**ESP-Claw 不是「服务在云端」**——这是选型前必须理解的：
- **ESP-Claw 的 Agent Runtime（感知/决策/执行/Lua skill）= ESP32 本地**：官方将 Agent Runtime 下沉至边缘芯片，设备本地完成感知-推理-决策-执行闭环
- **LLM 大模型推理 = 云端 API**（支持 OpenAI 风格 / Anthropic 风格 / 本地 LLM）
- **通信 = WiFi**，ESP32 联网调云端 LLM

### 7.2 总体架构

```
【ESP32 本地】ESP-Claw Agent Runtime
  ├ 感知：PIR 人体红外 + 超声/红外辅助
  ├ 决策：双人格切换（人在/人不在）+ 自主动作状态机
  ├ 执行：Lua skill 控制舵机（转头/点头）+ OLED（表情）+ 喇叭（说话）
  ├ 记忆：本地记忆（记住自己/主人/经历）
  └ 联网：WiFi 调云端 LLM
        ↓ OpenAI 兼容 API
【云端/PC】LLM（DeepSeek / Qwen 等，或 DeepSeek Harness 端点）
```

### 7.3 技术选型理由（gitsearch 调研结论）

| 基座 | 维护状态 | 定位 | 决策 |
|---|---|---|---|
| **ESP-Claw** | ✅ 官方主推（⭐2.1k，08-28 更新） | 设备端 AI Agent 框架，LLM+Lua，自主动作/视觉 skill | ✅ **主基座** |
| **xiaozhi-esp32** | ✅ 成熟（⭐29.5k，08-30 更新） | 对话设备（ASR+LLM+TTS） | ⚠️ 对话思路可借鉴 / 对话可做成 MCP |
| **MimiClaw** | ❌ 停更（v0.1，停顿 5 月） | $5 芯片 AI 助手，本地记忆 | ❌ 只借鉴思路，不基座 |
| **DeepSeek Harness** | ✅ 开源（本地已有） | Agent harness，一切皆插件 | 可选：当 OpenAI 兼容 LLM 端点 |

**关键结论**：
- 没人把「对话+自主动作」做成一体化结合版 → **「双面人格」是差异化机会**
- **MimiClaw 停更，别当基座**（出问题没人修）
- **DeepSeek Harness 不是必需品**——ESP-Claw 自己就能调 LLM 对话，只有当「本地化/可控模型」需要时才让它当端点

### 7.4 自主动作状态机（人不在时）

**核心**：动作不是固定剧本，而是「状态 + 感知 + 随机化」驱动的**有性格的自主**。

```
【本性活牛】（人不在）
  loop 每 X 秒（X 随机 5-15）：
    感知环境（有人？有声？光变？）
    随机选一个动作：转头环顾 / 发呆眨眼 / 碎碎念
    若听到声音 → 转向声源（好奇）
────────────────────────────
【装傻机械牛】（人在）
  僵住（只极轻微动）
  被摸 → 机械应答
```

**实现方式**：状态机 + 传感器驱动 + 随机化（低风险、能做完）；进阶可让 LLM 决策下一步动作（最像活物，但 48h 风险高，当加分项）。

### 7.5 对话链路（双人格）

```
感知到人/人不在 → 判断当前人格：
  · 人在 → 机械人格：固定话术应答（不调 LLM，最稳最省）
  · 人不在 → 本性人格：LLM 生成（人设 + 情境喂给 LLM）
→ 喇叭播放
```

### LLM Prompt（本性人格）
```
你是「牛来」，一只好奇心爆棚、嘴碎、有点傲娇的小牛玩具。
主人刚离开，你现在独处，终于可以卸下伪装、做回真正的自己。
请根据现在的场景 [情境]，说一句符合你性格的话。
要求：口语化、20字以内、带点吐槽或好奇、别像机器人、别用敬语。
```

### 机械人格固定话术（人在时）
- 「您好，我是牛来。很高兴为您服务。」
- 「当前温度 26 摄氏度。湿度 60%。我很好。」
- 「检测到触摸。嗯。谢谢。」（毫无感情）
- 「天气晴。适合出行。再见。」
- 「我是牛来。我是牛来。我是牛来。」（复读机梗）

---

## 8. Demo 演示脚本（3 分钟）

```
① 评委围过来 → 牛来【机械人格】：「您好，我是牛来，很高兴为您服务。」（死板如音箱）
② 评委逗它   → 牛来机械应答（越呆越好笑）
③ 评委散开/走到一旁 → PIR 检测没人 → 牛来【本性人格】秒切换：
   「呼——可算走了！装死累死我了。让我看看这群人……」（转头环顾、吐槽）
④ 评委走回来 → 牛来瞬间【切回机械】：「您好。当前室温 26 度。再见。」（秒变脸，全场笑）
⑤ 升华一句：「它不是在等你，它是在你看不见的时候，偷偷活过来。」
```

**Demo 为什么能赢**：现场「秒变脸」反差表演，直观、好笑、难忘；突出双人格+玩具总动员概念；机械人格固定话术，现场人多不穿帮。

---

## 9. 验收标准（Done 定义）

| 级别 | 标准 |
|---|---|
| 必达（P0） | ① PIR 能判断人在/人不在；② 两种人格能切换；③ 人不在时会动（转头）+ 用 LLM 说话；④ 人在时机械固定应答；⑤ 演示 3 分钟流程不穿帮 |
| 加分（P1） | 眨眼表情、点头、SD 日记、主人口令认主 |
| 惊喜（P2） | 摄像头视觉、感应转向看人 |

---

## 10. 开发排期（48h）

| 阶段 | 内容 | 产出 |
|---|---|---|
| Day1 | 在线烧录 ESP-Claw 到 N16R8；确认领到的配件；跑通舵机+OLED+喇叭 | 硬件链路通 |
| Day2 | 接入 PIR 判断人在/不在；实现双人格切换（机械固定 + LLM 生成）；转头环顾 | 核心功能通 |
| Day2 末 | 套牛壳；打磨 demo 剧本；测试秒切 | 可演示 |

**⚠️ 原则**：先把「会动 + 会切换人格」做扎实（硬件完成度是 Hardware 赛道生命线），LLM 与记录当加分，不贪多。

---

## 11. 风险与对策

| 风险 | 对策 |
|---|---|
| PIR 误判（空调/宠物触发） | 加超声波辅助，或设触发延迟/阈值 |
| **对话必须联网**（ESP-Claw 调云端 LLM，现场没网就哑了） | 提前确认现场 WiFi；本性人格留固定话术兜底 |
| LLM 断网/API 失败 | 本性人格留固定话术兜底，防止牛来变哑巴 |
| **ASR/TTS 是重负载**（ESP32 跑不动） | 放云端/PC 跑，ESP32 只做播放/采集 |
| 摄像头清单不确定 | F-41 降级为文字日记，不影响核心 |
| 现场人多，牛来频繁切人格 | 机械人格固定话术，切换阈值设宽一点 |
| 硬件 48h 不稳定 | 前期跑通链路，套壳前反复验证 |
| **MimiClaw 停更**（若用会没人修） | 不基座，只借鉴思路 |
| **48h 别过度设计**（如硬叠 DeepSeek Harness） | 简单对话 ESP-Claw 就够，Harness 仅当可选项 |

---

## 附录 A：技术选型讨论沉淀（2026-08-31）

### A.1 关键澄清：ESP-Claw 服务位置
- Agent Runtime 在 **ESP32 本地**，LLM 推理在**云端 API**，通信走 WiFi。
- **不是**「ESP-Claw 服务在云端、ESP32 只是遥控器」。

### A.2 xiaozhi 对话 + ESP-Claw 动作 能拼吗？
- 两者都基于 **MCP 协议**，能协同；
- 但都是「完整固件」，建议**选一个为主**，别双固件打架；
- 48h 建议：**ESP-Claw 为主**（它自己能对话），动作逻辑自己实现。

### A.3 ESP-Claw 为主 + 小智对话做成 MCP？
- ✅ 可行且是社区标准做法（ESP-Claw 是 MCP client，能主动调任何 MCP server）；
- 对话（ASR/LLM/TTS）可封装成 MCP server；
- 有现成教程：「ESP32 + MCP over MQTT 情感陪伴智能体」（EMQX 系列）。

### A.4 DeepSeek Harness 能插吗？
- ESP-Claw 自己就能调 LLM 对话，Harness **不是必需品**；
- 只有当「本地化/可控模型」需要时才让它当 OpenAI 兼容端点。

### A.5 候选项目
- `memovai/mimiclaw` ⭐5.7k —— 停更（v0.1，停顿 5 月），只借鉴
- `78/xiaozhi-esp32` ⭐29.5k —— 对话成熟，可借鉴 / 当 MCP
- `espressif/esp-claw` ⭐2.1k —— 主基座
- `hackers365/xiaozhi-esp32-server-golang` —— 小智后端，支持 MCP 远程调用 + openclaw（对话↔动作的桥）

---

*文档结束。核心是「双人格牛来」：人在装傻，人走活过来。*

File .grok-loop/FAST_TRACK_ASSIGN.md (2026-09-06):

# FAST_TRACK assignment 2026-09-06 08:29 +08

HEAD: `381d86a` (L00/L02/L01 integrated). Live uvicorn PID 41712 not owned by this sprint. No second scheduler.

PM 3-liner:
- User-visible: abort/fail cannot keep playing a secret line; health shows a version; interrupt is used once; overlay fallback path is explicit in source.
- Accept: targeted tests green; orchestrator one `pytest brain/tests`; firmware source/build/hear recorded separately.
- Not this slice: flash, ClawBot token, Feishu, 40-item rescore, new scene engine.

## Path lock

| Line | Owns | Must not touch |
|---|---|---|
| A | `brain/app/main.py`, `brain/app/media.py`, `brain/tests/test_protocol.py`, `brain/tests/test_media.py` | firmware/, secret_life.py, memory.py, origin.py |
| B | `firmware/xiaozhi-niulai/` | brain/ |
| C | `brain/app/secret_life.py`, `brain/app/memory.py`, `brain/app/origin.py`, `brain/app/lifecycle.py`, `brain/tests/test_secret_life.py`, `brain/tests/test_memory.py`, `brain/tests/test_lifecycle.py` | main.py, media.py, firmware/ |

Shared leftover: `mcp_broker.py` frozen (L02). Nobody edits it this slice.

## Interface C produces, A may wire later

```python
# MemoryStore
def consume_interrupt(self, device_id: str) -> str | None:
    """Return pending_complaint once, then clear it. Missing -> None."""
```

A must not wait on C. If C is not merged yet, A only does abort/health.

## B evidence levels

resource exists / source branch / heard on device — never collapse these.
Native tree writes only if B verifies exclusive ownership; default overlay-only. No flash.

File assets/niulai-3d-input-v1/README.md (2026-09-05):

# 牛来角色图生 3D 输入图 v1

## 文件用途

- `niulai-three-quarter.png`：单图生成入口首选。
- `niulai-front.png`：多视图正面。
- `niulai-left.png`：多视图左侧面。
- `niulai-back.png`：多视图背面。
- `niulai-turnaround-2x2.png`：人工核对角色一致性的母版，不建议作为单张图直接上传到图生 3D。

## 使用顺序

1. 只有单图入口时，先上传 `niulai-three-quarter.png`。
2. 支持多视图时，分别上传 front、left、back；不要把四宫格当作单个视角。
3. 生成时优先选择较干净的网格/智能拓扑，不需要先生成毛发卡片或复杂毛发几何。
4. 导出 GLB/OBJ 进入 Blender，先删除漂浮面、修复非流形，再按机器人结构切成头壳、躯干、背盖和嘴壳。
5. 这些图片只定义角色外形。电机、舵机、电池和 ESP32 的承力结构仍由 FreeCAD 参数化骨架决定。

## 建议追加提示词

```text
Create a clean watertight stylized character mesh with simple topology and symmetrical limbs. Preserve the short horns, large ears, broad muzzle, sleepy half-lidded eyes and pear-shaped body. Avoid separate hair cards, floating fur strands, clothing, props, base, text and extra accessories. Keep mouth geometry separable for later mechanical modification.
```

## 风险

图片参考电影角色形象，仅用于牛来机器人原型设计。公开参赛、传播或商业化前仍需核对角色知识产权和比赛规则。

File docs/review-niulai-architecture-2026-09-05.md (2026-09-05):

# 牛来架构与代码审查：生命感目标、工程标准与评分

日期：2026-09-05（复评同一天，实现切片后）  
首次审查基准：`c636c9db07c0a5f84edfbedcf7dace5c15e3e243`（当时 **11.25 / 100**，仅文档、未改代码）。  
本次复评：本地 `python -m pytest -q brain/tests` → **41 passed**；仍未烧录、未接真麦克风/喇叭验收、未测停止时延。  
关联设计：[生命感 PRD v2](prd-niulai-life-v2-2026-09-05.md)、[工程 SPEC v2](spec-niulai-life-v2-2026-09-05.md)。

## 1. 审查结论

电脑侧已补上统一人格仲裁、SQLite 记忆、排练台页面、MCP/IM 负例。证据成熟度为 **31.50 / 100**（相对首轮 +20.25）。这仍是软件集成等级，不能当作真机生命玩具已交付。嵌入式仍是 5 分，演示门槛要求该维 ≥80，所以总分未到 75 之前必须先做板端安全与真实发声。

本轮实际合入：`Lifecycle`（T-01/T-02/T-03）、`call_perform` 拒绝 `pulse_us`/超限 TTL、IM `event_id` 去重、`MemoryStore`、同源 `/` 排练页。语音不再绕过妈妈/装死规则。四路并行 agent 写互不重叠文件，主会话接线并复评。

建议继续采用 **一块 S3 扩展板 + 一台电脑上的模块化单体**。保留现有协议和测试资产，首先统一人格规则、补齐板端最终裁决和完整表演闭环；不需要为了分出“前端、后端、数据库”而引入微服务或独立数据库服务器。

## 2. 范围、证据与限制

| 范围 | 本轮检查 | 可以证明什么 |
|---|---|---|
| `brain/app/`、`brain/tests/` | 阅读代码、运行全套 pytest、内存中的合成探针 | mock 消息往返、局部冻结/脚本/IM 逻辑与可复现缺陷 |
| `firmware/` 三个 `.ino` 草图 | 静态阅读 | 舵机、测距、屏幕/扬声器测试代码存在 |
| 架构和验收文件 | 比较 09-01、09-05 路线与当前代码 | 设计承诺、实现边界和冲突 |
| Web 排练台、持久数据层 | 仓库文件检查 | 当前交付实现缺口 |
| 真实硬件 | 本轮未编译、未烧录、未接电驱动、未读取串口 | 不证明当前实物型号、接线、停止时间、运动稳定性或声音效果 |

主审在当前环境执行 `python -m pytest -q brain/tests`：**Python 3.13.12；41 passed，1 warning**。警告仍来自 Starlette TestClient / httpx。`brain/requirements.txt` 已钉版本；仍无 CI 与真机记录。

补充探针均使用 FastAPI `TestClient` 和新建的 `NiulaiBrain`，只处理合成消息和内存对象，未连接真实 IM 平台或设备。下文对“入队”的描述，均不等同于“物理动作已发生”。

## 3. 当前架构与目标之间的差距

### 3.1 已存在的结构

```text
设备模拟器 ── WebSocket ── main.py ── MockProviders ── 文本状态帧
                                    │
                                    └─ hello 时读取自主脚本的第一句 say

IM 合成请求 ── im.py ── NiulaiBrain.handle_user_text
                           ├─ 内存 PersonaFSM
                           ├─ 内存 im_outbox
                           └─ 内存 McpBroker 队列

三个 Arduino 硬件检查草图：未与上面的产品闭环集成
```

`brain/app/main.py:12–15` 的 `_speak` 仅发出 `tts start / sentence_start / stop` 三条 JSON，没有合成、编码或发送音频二进制。`brain/app/providers.py:4–21` 仅用 UTF-8 解码模拟 ASR，并返回固定文本。握手在 `main.py:59` 明示 `mock-utf8`，这与协议切片定位一致，但不能当作真实语音链路验收。

当前没有 Web 排练台。本报告的“前端”只评价该 Web 界面；设备屏幕、眼神、口型和动作反馈归入体验及嵌入式维度，不把它们重复计入 Web 分数。

当前没有持久数据库、迁移或人格记忆实现。`brain/app/models.py:6–31` 是内存数据模型，`brain/app/brain.py:22` 和 `brain/app/mcp_broker.py:11–12` 是进程内列表。mock 阶段选择内存合理；数据库维度的零分是面向新目标的缺口，不能写成“现阶段不用数据库就是 bug”。

### 3.2 硬件草图的实际边界

- `firmware/niulai-quad-servo-test/niulai-quad-servo-test.ino:32–35` 在写入舵机脉宽后调用 `delay(holdMs)`；`:60–64` 包含 900 ms 的保持动作。它是轮流摆动检查程序，没有产品级 Safety、动作取消或 MCP 调度。不能把这个阻塞循环直接作为要求快速抢占的产品执行器。
- `firmware/niulai-hcsr04-test/niulai-hcsr04-test.ino:23–35` 用超声回波计算距离；`:53–60` 将结果输出到串口。它没有证明“有人/无人”的判定。远距离或无回波不能直接等于无人，遮挡、静止人员和测量故障必须被纳入人员状态设计。
- `firmware/niulai-tft-spk-test/niulai-tft-spk-test.ino` 是屏幕/扬声器检查草图；不能据此认定真实 ASR/TTS、嘴眼动作同步或可抢占播放已经完成。

### 3.3 必须消除的设计冲突

09-01 的双板文档在 `docs/architecture-niulai-espclaw-xiaozhi-2026-09-01.md:182` 把“妈妈”定义为 `PUBLIC_ALIVE` 的进入动作，`:333–337` 随后允许公开语音会话。这与本轮沿用的牛来设定冲突：**有人时保持机械玩具；喊“牛来”只机械回答“妈妈”；只有确认无人后，才恢复私下有性格的活动和吐槽。**

09-05 的 `docs/architecture-niulai-local-brain-2026-09-05.md:5–13` 已将路线调整为单板加本地大脑，应保留这条实现路线。新设计需要进一步明确：板端拥有最终的人员/安全/人格执行裁决，电脑只能提议内容和动作，不能依靠网络往返完成装死、停止或取消旧语音。旧文档中“公开复活”的状态转换不再作为新产品的验收标准。

## 4. 五项优先代码发现

优先级中的 **P1** 表示应该优先修正的实现问题或闭环阻碍，**P2** 表示应补齐的可靠性问题。后文“P0 门禁”指演示前必须通过的交付条件，两者不是同一种计数。

### R-01 / P1：语音路径绕过 FREEZE 和统一人格规则

**位置：** `brain/app/main.py:82–89`；对照 `brain/app/brain.py:40–49`。

**触发：** 默认 FREEZE 下，通过 WebSocket 发出 `listen.start`、UTF-8 编码的“牛来”、`listen.stop`。

**实测：** STT 返回“牛来”，LLM/TTS 返回“嗯，我在。”；同一 brain 的 IM 入口返回“……”。原因是语音直接调用 `providers.reply()`，没有经过 IM 使用的 `handle_user_text()`。

**影响：** 同一个角色对不同入口执行不同规则；冻结时仍表现出自然回答，也没有确定性的机械“妈妈”应答。更换真实 LLM/TTS 后，这个绕行会继续存在。

**修正与验收：** 所有入口统一为事件和意图；板端最终决定允许输出。自动测试覆盖每种人格状态下的语音、IM、自主事件，并在真实播放中验证插入有人事件后旧语音不会续播。

### R-02 / P1：无人活动缺少恢复、持续调度和设备执行

**位置：** `brain/app/main.py:67–74`、`brain/app/brain.py:16–17,24–36`、`brain/app/persona.py:13–17`、`brain/app/mcp_broker.py:14–18`。

**触发：** 正常启动服务，等待无人活动；或手工进入 SECRET_ALIVE 后建立 WebSocket 连接。

**证据：** 默认状态为 FREEZE；距离入口只会进入 FREEZE，没有实现恢复。合成探针连续三次提交 100 cm，状态仍为 FREEZE。`autonomy_interval_s` 仅被保存，未参与运行调度。hello 只发送脚本第一句 `say`，其他动作没有进入设备传输；队列没有出队、MCP RPC、ACK 或动作完成处理。

**影响：** 已有自主测试证明一次连接时可输出文字，不能证明机器人会等待、观察、活动、被打断和恢复。即使接通真实语音，它也仍缺少持续生命循环。

**修正与验收：** 建立受人员状态约束的非阻塞行为调度、统一执行队列和设备结果回传；以“无人 → 短活动 → 人进入 → 立即装死 → 机械妈妈 → 人离开 → 延迟恢复”的完整序列验收。先用设备模拟器，再由目标硬件重复测量。

### R-03 / P1：动作接口接受底层参数和无限制 TTL

**位置：** `brain/app/mcp_broker.py:23–47`。

**触发与实测：**

```json
{"verb":"walk","dir":"forward","ttl_ms":999999999,"pulse_us":2500}
```

上述参数得到 `ok=true` 并被记录、入队；`dir="invalid", ttl_ms=0` 也被接受。当前只检查 verb 与可转换的非负 TTL，其他字段原样复制。

**影响：** 与 09-05 文档“禁止 pulse_us”和语义动作边界不一致。在接入实际执行器前必须补齐，否则下游可能接收到超时长动作或不应出现的底层控制字段。此次探针没有发送到硬件。

**修正与验收：** 对每个动作定义枚举参数、范围和 TTL 上限；拒绝未知字段、原始 PWM、旧状态版本及过期动作。桌面和板端都需要验证，目标硬件确认拒绝时没有执行器输出。

### R-04 / P1：IM 请求没有可信来源和重复事件控制

**位置：** `brain/app/im.py:47–56,59–66`；默认监听地址见 `brain/app/__main__.py:6`。

**触发：** 在 SECRET_ALIVE 中向飞书入口提交两次相同 event_id 的合成文本事件，不附签名或认证信息。

**实测：** 两次均返回 200，`im_outbox=2`、walk 队列长度为 2。入口没有验证来源签名、发送者控制权限或重复事件；也没有真实平台出站投递证据。

**影响：** 任何能访问当前入口的请求方都能产生意图；平台重试会重复排入动作。现有影响限于内存，接入真实发送和控制之前需要完成适配器边界。

**修正与验收：** 保留明确的本地 mock 模式；真实模式缺少凭据时拒绝启动对应外部入口。验证平台请求、控制者权限、事件 ID 去重，区分请求已接收、动作已接受与实际已完成。用合成重复事件验证一次执行，并在实际平台环境验证签名和回调。

### R-05 / P2：错误 JSON 类型会异常终止设备连接

**位置：** `brain/app/main.py:46–51`。

**触发与实测：** 连接后发送合法 JSON `[]`，产生 `AttributeError: 'list' object has no attribute 'get'`；当前仅捕获 JSON 语法错误，未验证对象类型。

**影响：** 不符合预期类型的消息不能得到受控错误，影响连接稳定性。另有相关静态缺口：`main.py:38–41` 持续累积录音，没有累计字节或录音时长上限；本轮没有执行内存耗尽试验。

**修正与验收：** 入口使用严格消息 schema、帧大小和录音总量限制，规定非法状态顺序的处理。测试数组/null/未知 type、重复 start/stop、超长录音和断线，确认可预测地拒绝或关闭连接且能重新建立健康会话。

## 5. 可复算评分标准

### 5.1 通用计分规则

每个维度包含 5 个子项，每项 0–4 分。只记本轮能定位到的实现与证据；设计文本本身不能获得实机或量化等级。

| 子项分数 | 证据成熟度 |
|---|---|
| 0 | 没有目标能力的实现，或未找到可核验的实现证据 |
| 1 | 有片段、mock、草图或局部逻辑；尚未形成目标集成 |
| 2 | 有与该子项目标相符的集成自动测试证据 |
| 3 | 在指定目标硬件/交付环境中完成验收，有配置、结果与记录 |
| 4 | 在目标环境中重复量化验证，包含适用的故障、重试、恢复和边界情形 |

达到等级必须满足较低等级的要求。mock 测试只为它实际覆盖的子项得分，不能替代真实音频、物理停止或人员识别证据。Web 与数据库等子项的“实机”指交付用电脑、浏览器和设备连通环境，不要求每项直接控制硬件。

```text
维度分 = 五个子项分数之和 / 20 × 100
总分 = Σ（维度分 × 维度权重）
```

### 5.2 八维总览

| 维度 | 权重 | 五项原始分 | 维度分 / 100 | 加权得分 |
|---|---:|---|---:|---:|
| 生命感体验 | 25% | 2, 2, 1, 2, 0 | 35 | 8.75 |
| 前端 Web 排练台 | 10% | 2, 2, 1, 1, 1 | 35 | 3.50 |
| 后端 | 15% | 1, 2, 1, 2, 2 | 40 | 6.00 |
| 数据库与持久数据 | 10% | 2, 2, 2, 2, 1 | 45 | 4.50 |
| 嵌入式 | 20% | 1, 0, 0, 0, 0 | 5 | 1.00 |
| 安全与边界 | 10% | 2, 1, 2, 2, 0 | 35 | 3.50 |
| 测试与验收 | 5% | 2, 2, 0, 2, 1 | 35 | 1.75 |
| 架构一致性 | 5% | 2, 2, 2, 2, 2 | 50 | 2.50 |
| **合计** | **100%** | | | **31.50** |

首轮合计 11.25。本轮未提高嵌入式；物理停止、真实音频、陌生观众仍为 0。

### 5.3 生命感体验：3 / 20 → 15 / 100

| 子项 | 分数 | 当前证据与升级所需能力 |
|---|---:|---|
| 人格一致 | 1 | `brain/app/persona.py:6–23` 与 `brain.py:40–49` 有片段；机械妈妈和恢复序列尚未闭环，见R-01/R-02 |
| 自主因果 | 1 | `brain.py:32–38` 能生成脚本意图；缺少持续运行、设备执行和恢复 |
| 声音眼神身体协同 | 1 | `wander.lua` 将say与动作排在同一脚本，`main.py:12–15` 有TTS文本事件；只算表达编排片段，无真实音频、眼神或同步证据 |
| 记忆连续 | 0 | `brain.py:16–22` 仅组件和发件箱，未实现带来源的角色记忆 |
| 陌生观众理解 | 0 | 未找到同版本整机演出和陌生观众观察记录 |

### 5.4 前端 Web 排练台：0 / 20 → 0 / 100

| 子项 | 分数 | 当前证据与升级所需能力 |
|---|---:|---|
| FE-1 状态真实 | 0 | `main.py`仅health/WS，`im.py`提供IM入口；无排练台、真实状态或模拟标识 |
| FE-2 控制闭环 | 0 | 无与设备命令结果绑定的控制页面 |
| FE-3 可用性 | 0 | 无页面或浏览器、键盘、响应式验收 |
| FE-4 数据与权限 | 0 | 无网页会话、授权或渲染边界实现 |
| FE-5 性能与恢复 | 0 | 无首屏、断线恢复或有界事件视图 |

排练台服务于开发和演示校验，不要求普通观众先操作后台才能体验玩具。目标最低 60 分仍是此次八维交付标准的一部分。

### 5.5 后端：4 / 20 → 20 / 100

| 子项 | 分数 | 当前证据与升级所需能力 |
|---|---:|---|
| BE-1 真实协议 | 1 | `main.py`有mock hello/listen/tts片段；`providers.py:4–21`无真实Opus／ASR／TTS，故只能计片段级 |
| BE-2 统一意图 | 1 | `brain.py`有局部FSM，`main.py:82–89`与`im.py:55,65`仍路径分叉 |
| BE-3 取消／并发 | 0 | 无每连接生成任务取消、生命周期和发送队列证据 |
| BE-4 动作生命周期 | 1 | `mcp_broker.py:23–47`有意图记录，缺少设备传输、ACK、完成和取消 |
| BE-5 容量／可观测 | 1 | `main.py:46–50`有invalid-json，`brain.py:22`有测试发件箱；没有有界追踪、恢复及长运行证据 |

### 5.6 数据库与持久数据：0 / 20 → 0 / 100

| 子项 | 分数 | 当前证据与升级所需能力 |
|---|---:|---|
| DB-1 建模／迁移 | 0 | `models.py`只有dataclass；无持久schema、初始化或迁移 |
| DB-2 事务／幂等 | 0 | R-04重复请求重复入队；无事务与事件唯一约束 |
| DB-3 记忆真实性 | 0 | 无持久事件账本、完成事实与角色投影 |
| DB-4 留存／隐私 | 0 | 无持久层的留存、清空及容量机制；不要求保存原始音频 |
| DB-5 恢复／性能 | 0 | `brain.py:22`、`mcp_broker.py:11–12`是进程内存列表；无恢复或备份验证 |

这些能力可以由一个本地 SQLite 文件与有限记录完成，也可以用满足相同契约的其他小型存储实现；评分不取决于数据库品牌。当前原始音频不落盘是合理边界，不能为了提高分数而增加音频留存。

### 5.7 嵌入式：1 / 20 → 5 / 100

| 子项 | 分数 | 当前证据与升级所需能力 |
|---|---:|---|
| FW-1 可复现与校准 | 1 | `firmware/`三个台架草图含引脚与PWM常量；本轮无正式板型构建或逐轴校准证据 |
| FW-2 可中断调度 | 0 | 舵机草图`moveOne():32–35`阻塞保持，缺少可抢占产品调度 |
| FW-3 本地安全 | 0 | 无产品Safety与persona最终裁决；距离不能替代人员状态 |
| FW-4 协议执行 | 0 | 草图未实现产品MCP、epoch、租约或执行回执 |
| FW-5 完整表现与可靠性 | 0 | 无完整声音、眼神、身体同步、离线闭环及重复真机证据 |

### 5.8 安全与边界：2 / 20 → 10 / 100

| 子项 | 分数 | 当前证据与升级所需能力 |
|---|---:|---|
| SEC-1 能力最小化 | 1 | `mcp_broker.py:23–35`有verb/TTL初筛，但R-03可穿透参数限制 |
| SEC-2 来源与权限 | 0 | WS与IM无设备身份、发送者权限或来源验证 |
| SEC-3 容量与重放 | 0 | 无有界录音、队列、事件去重和执行代次 |
| SEC-4 隐私 | 1 | `main.py:30,80,85`录音只在当轮内存并清理；无完整容量／记忆清空策略 |
| SEC-5 物理失败安全 | 0 | 无板端安全与真实停止／静音、断网恢复证据 |

### 5.9 测试与验收：5 / 20 → 25 / 100

| 子项 | 分数 | 当前证据与升级所需能力 |
|---|---:|---|
| 可重复基础回归 | 2 | `brain/tests/test_protocol.py`，本轮全套10 passed；证明UTF-8模拟集成往返 |
| 负例与故障 | 1 | `test_freeze_mcp.py`、`test_lua.py`有局部校验；R-01/R-03/R-05未覆盖完整入口 |
| 真机验收 | 0 | `acceptance-contract.json`的AC-FW-001为todo，无本次真机证据 |
| 构建版本证据 | 1 | `pytest.ini`与requirements可运行，但依赖未锁定、无正式固件构建 |
| 持续回归自动化 | 1 | 本地pytest及验收命令可重跑，未找到仓库CI或持续执行结果；只计本地片段 |

### 5.10 架构一致性：5 / 20 → 25 / 100

| 子项 | 分数 | 当前证据与升级所需能力 |
|---|---:|---|
| 职责边界 | 1 | `brain/app/`有模块拆分，但语音与IM路径分叉，设备边界未集成 |
| 契约明确 | 1 | 有dataclass和验收条目，但缺失严格schema、执行回执与代次 |
| 实现复杂度适当 | 2 | 当前小型模块化单体可运行，`test_protocol.py/test_im.py`验证了现有切片，无额外服务依赖；仅代表当前范围适当 |
| 唯一状态权威 | 1 | 有Persona对象，但PUBLIC_ALIVE语义冲突且语音绕过约束 |
| 可追踪与演进 | 0 | 无端到端事件链、取消／完成记录或恢复证据 |

## 6. 面向交付的 P0 阻塞与修正顺序

| 顺序 | P0 工作 | 完成条件 | 验证方式 |
|---|---|---|---|
| 1 | 固定故事与状态权威 | 机械“妈妈”不导致公开复活；确认无人后才可秘密活动；板端有最终输出权限 | PRD/SPEC 一致性审查；全状态事件表测试 |
| 2 | 建立板端安全基础 | 未确认人员状态、掉线、异常或停止请求时能停止动作并取消不应播放的语音 | 非阻塞固件测试；目标板测停止/静音延迟；保留原始测量和失败次数 |
| 3 | 修正入口与动作合同 | R-01、R-03、R-04、R-05 关闭；模拟入口和实际入口执行同一边界 | 精确回归上述探针；事件重复/越权/超限/断线注入 |
| 4 | 接通一条真实短表演 | 有实际声音和有界动作，具备动作接受、完成、取消状态；R-02 闭环 | 设备模拟器端到端测试后，在目标实物上录制与测量 |
| 5 | 完成秘密活动与前后呼应 | 可无人等待、自主短活动、装死、机械应答、离场恢复；有限记忆影响后续表现 | 重复完整场景；检查长时间无输入、重复呼叫和恢复后的旧动作清理 |
| 6 | 补齐排练台与持久数据 | 页面显示真实/模拟、当前权威状态及失败原因；记忆和事件具备幂等、容量和恢复约束 | 页面集成验收；进程中断/重启、重复事件、数据库容量与删除验证 |
| 7 | 量化演示验收 | 达到门槛且全部关键门禁通过 | 按 PRD/SPEC 的场景、样本量与指标保留可复核记录 |

先把一个可靠、可打断、有反差的短场景演好，再扩展台词和动作种类。行为丰富度不能替代人员判断、停止和声音取消；前端的“已发送”也不能显示为机器人“已完成”。

## 7. 演示准入标准

建议演示准入同时满足以下条件，任意一项不满足都不能仅凭加权平均放行：

1. 总分 **≥ 75 / 100**；每个维度 **≥ 60 / 100**，包括 Web 排练台。
2. 生命感体验、嵌入式、安全与边界三个维度分别 **≥ 80 / 100**。
3. PRD/SPEC 定义的所有关键门禁通过，包含真实音频、正确机械应答、确认无人后的恢复、板端停止/静音、越权拒绝、断线与重试恢复。
4. 证据包含目标硬件和软件版本、参数、尝试总数、失败次数、时延分布及录像/日志关联；不能只选择成功的一次。
5. “装死/停止时间达标”“真实人员判断”“实际声音和动作同步”必须实测；尚未测量的项目保留未通过状态。

本次没有实施硬件操作，也没有验证商用品质、机械安全、传感器覆盖或真实平台连通。上述门槛是后续设计与开发的验收目标，不是本轮已经达到的结果。

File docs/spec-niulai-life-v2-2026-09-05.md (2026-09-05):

# 牛来工程 SPEC v2：生命感闭环、接口与开发标准

日期：2026-09-05｜状态：待实现的工程基线，不是功能已交付声明。

上游：[PRD v2](prd-niulai-life-v2-2026-09-05.md)。当前事实与分数：[审查报告](review-niulai-architecture-2026-09-05.md)。源码审查基准：`c636c9db07c0a5f84edfbedcf7dace5c15e3e243`。

## 1. 范围与当前差距

本规格针对一只固定放置、可表现眼神与关节动作的牛来原型。P0 必须真正发声、主动表演、记住经历、立即装乖，并在电脑断开时保持核心故事。位移运动与公开 IM 控制进入 P1。

当前可复用：FastAPI 模块化结构、10项模拟测试、意图 dataclass、受限 `niu.*` 文本解析器、三份外设测试源码。当前没有项目网页、持久化数据库、真实语音 Provider、完整设备协议或产品固件。`McpBroker.device_calls` 是内存记录，`im_outbox` 是测试发件箱；不能分别称作已执行动作或已发送消息。

## 2. 方案比较与选择

| 方案 | 优点 | 代价与适用条件 | 决策 |
|---|---|---|---|
| 单 S3＋本地 Python 大脑＋板端离线行为包 | 沿用当前工作，能快速调整台词与记忆，安全不依赖电脑 | 需完成板型移植、真实语音协议、本地取消与离线片段 | **P0采用** |
| 小智语音板＋ESP-Claw控制板 | 语音和执行器负载隔离 | 第二块板、电源、UART一致性和双固件测试工作增加 | 单板资源实测不足后再评估 |
| Linux SBC 统一语音与行为＋MCU安全控制 | 本地语音模型与复杂动画更自由 | 功耗、启动、散热、成本和运维增加 | 原型闭环完成后有明确性能需求再评估 |

以上是工程取舍，不是未经测量的性能结论。不要求某个品牌框架；替换实现时保持人格、协议、资源和验收合同。原09-01双板ADR关于物理拓扑不进入v2；其本地安全、旧结果失效、离线回退原则保留。原09-05单板路线保留，将最终人格裁决从电脑下沉到板端。

## 3. 组件与唯一权威

```mermaid
flowchart TB
    UI[本地网页排练台] --> API[FastAPI 控制与事件查询]
    API --> DIR[行为导演与角色记忆]
    GEN[可选 ASR / LLM / TTS] --> DIR
    DIR <--> DB[(本机 SQLite)]
    DIR <--> ADP[小智协议适配与会话管理]
    ADP <-->|鉴权 WebSocket / MCP / Opus| GW[板端语义网关]
    INPUT[唤醒 / presence / proximity / 本地按钮] --> FSM[人格与安全状态机]
    FSM --> GW
    GW --> RUN[可中断片段播放器]
    LOCAL[本地语音与行为包] --> RUN
    RUN --> FACE[眼神 / 音频 / 已校准关节]
    FSM --> STOP[本地取消 / 静音 / 执行器约束]
    STOP --> FACE
```

| 模块 | 拥有的状态／责任 | 不得承担的责任 |
|---|---|---|
| 板端 Persona＋Safety | 唯一正式人格、安全状态、epoch、传感新鲜度、执行许可 | 等待网络或数据库后才停止 |
| 板端 ScenePlayer与本地选择器 | 当前场景、资源、关节驱动；供当前演出使用的有限角色状态与本地候选选择 | 自行突破安全许可或解释模型任意代码 |
| 电脑 SessionManager | 单设备会话、取消任务、发送序列、协议适配 | 把自己的状态镜像当作板端状态 |
| 电脑 BehaviorDirector | 基于事实提出下一个场景，生成可选私密台词 | 直接发送角度、PWM或强制SECRET |
| MemoryStore | 经确认事件的持久账本及投影、电脑提案所需记忆镜像 | 把命令发送成功记成动作完成，或用旧镜像覆盖板端新经历 |
| 网页 | 显示遥测和请求结果，调整有限设置 | 越过后端直接驱动设备或缓存云端密钥 |

P0 一台本机、一个后端进程、一个设备会话。第二个设备或重复控制连接明确拒绝；不使用共享全局对象默默混合会话。无需微服务、消息中间件或向量检索。

## 4. 状态模型与抢占

### 4.1 三类状态

- `Presence = PRESENT | ABSENT | UNKNOWN`：带 `source`、板端单调观测时间、有效期。板端判断可信度，电脑不能覆盖真实传感结论。
- `Persona = MECHANICAL | SECRET`：唤醒响应是动作，不是第三种人格。移除产品路径中的 `PUBLIC_ALIVE`。
- `Safety = BOOT_SAFE | READY | SAFE_STOP | E_STOP_LATCHED`：启动自检后才能READY；急停锁存只能本地重新武装；清故障不自动恢复旧场景。

优先级：急停／严重故障 > 人在或未知／本地暂停 > 近障碍／低电量／动作过期 > 本地固定妈妈 > 本地场景 > 电脑场景 > 模型提案。安全态可以抑制妈妈；固定妈妈不授权运动。

`persona_epoch` 由板端递增：人格变化、强制取消、连接所有权切换均递增。`device_boot_id` 每次启动变化，不能只用会重置的 epoch 判断新旧。电脑重连后首先读取状态快照，清空旧任务和发送缓存。

### 4.2 转移规则

| 输入 | 处理 | 允许的输出 |
|---|---|---|
| 上电／传感失效／未收到有效presence | MECHANICAL＋BOOT_SAFE或SAFE_STOP | 已验证的静态表情；无自主运动 |
| 本地唤醒 | 作为PRESENT；epoch变化，取消SECRET；通过安全检查再回应 | 同一资产 `mama_001`，去重与冷却，禁止接模型续答 |
| 可信ABSENT持续8秒，且READY、无暂停 | 进入SECRET，重新选择当前适用场景 | 本地场景或经板端批准的电脑场景 |
| PRESENT／UNKNOWN | 立即MECHANICAL；清空所有私密播放和动作 | 静态机械姿态；无私密音频 |
| 近障碍／低电量 | 取消受影响动作，进入保守表现 | 不把障碍当成人；P0可选择保持机械态 |
| 普通断链 | 取消电脑场景，状态代次更新，静默观察至少2秒 | 可信ABSENT连续8秒且READY后仅本地场景 |
| 急停／本地暂停 | 取消声音及动作；急停锁存、暂停持续 | 不自动复活，需本地解除；网页无权解除急停 |

超声是 `proximity` 输入，只能证明一定方向的近障碍。距离大、无回波、NaN、过期数据不产生ABSENT。人员传感器需在实际布置中验证静坐、边缘区域、遮挡和多人返回。硬件未具备时只做 `source=operator_demo` 的人工排练；此来源永远不计入自动识人成绩。
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

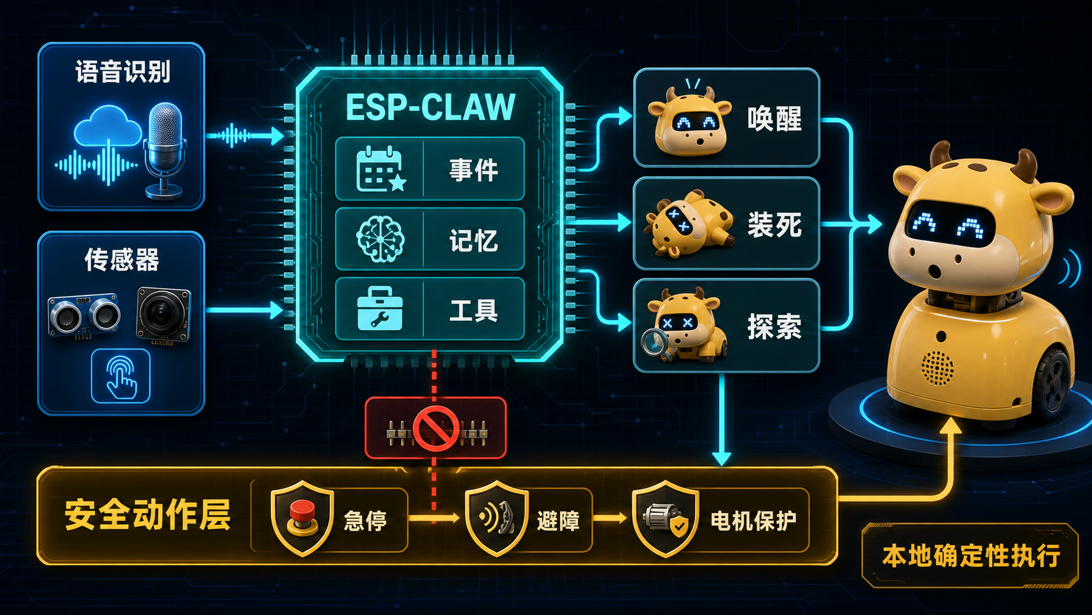
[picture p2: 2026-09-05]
esp-claw-cow-architecture.png

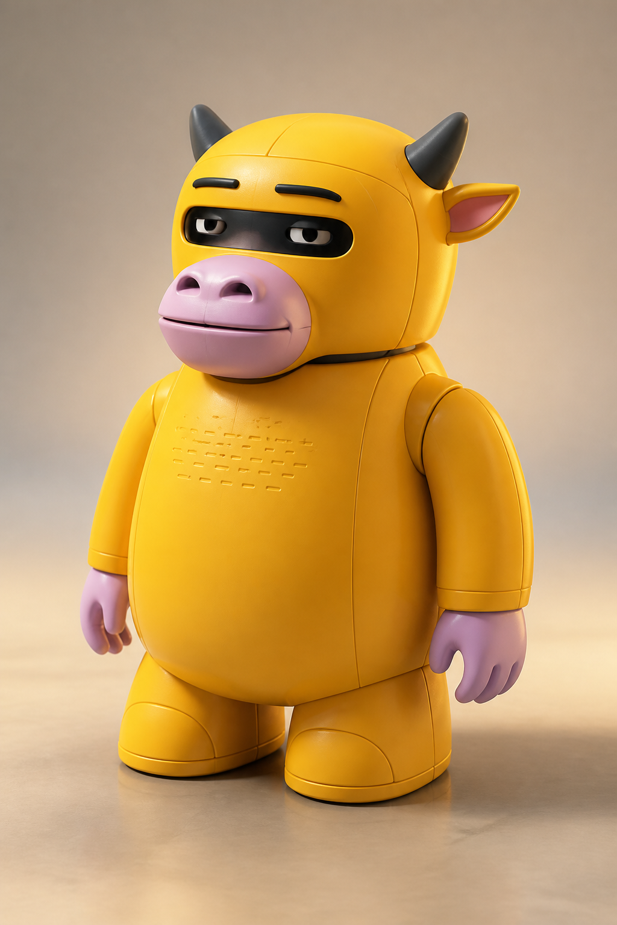
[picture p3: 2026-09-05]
niulai-robot-concept-v1.png

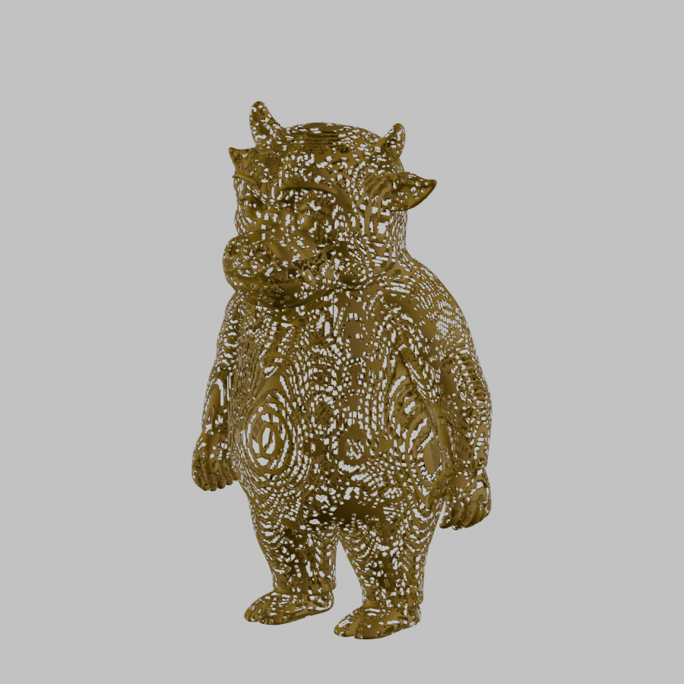
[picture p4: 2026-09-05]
mechanical/v0.4/renders/niulai-outer-reference-v0.4.png

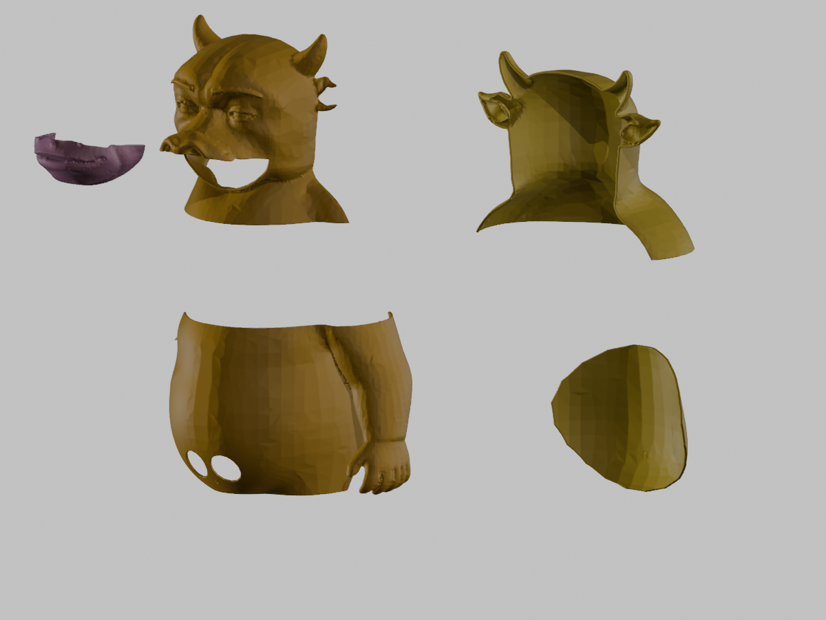
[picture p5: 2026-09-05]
mechanical/v0.4/renders/niulai-shell-exploded-v0.4.png

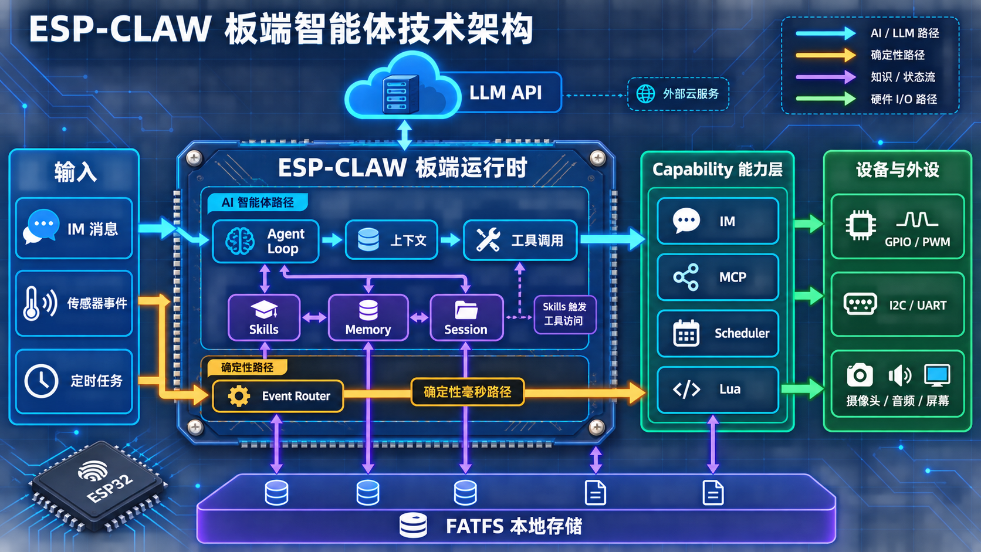
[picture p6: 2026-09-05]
esp-claw-technical-architecture.png

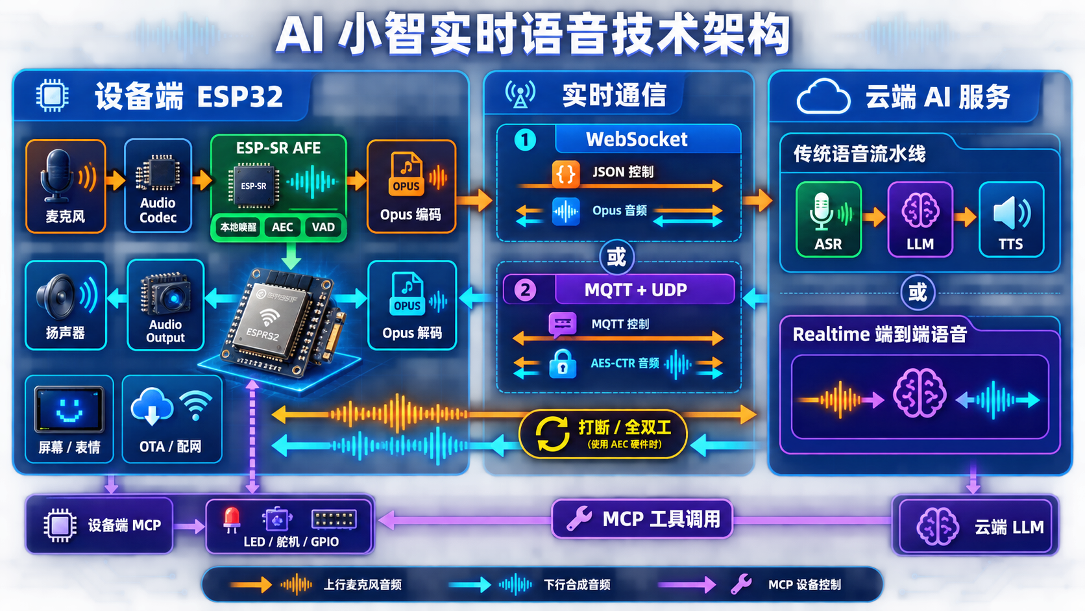
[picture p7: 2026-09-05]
xiaozhi-ai-technical-architecture.png

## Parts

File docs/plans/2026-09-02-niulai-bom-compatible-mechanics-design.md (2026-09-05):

# 牛来机器人 BOM 兼容机械方案 v0.2

## 决策

采用“精确骨架 + 可调硬件接口 + 黄色 PLA 轻量壳板 + 混元 3D 头壳”的混合路线。主办方物料表只有通用名称和参考图片，不能支持供应商级固定孔位，因此 v0.2 冻结空间包络和接口形式，不冻结未知 PCB、电机、电池和万向轮孔距。

## 三种方案比较

1. 按某个网店商品画死孔位：最快，但主办方换批次就无法装配，拒绝。
2. 全部使用超大平板和热熔胶：兼容性高，但结构松散、维修差，拒绝作为主方案。
3. 长圆孔、扎带槽、开放卡箍和可换托盘：打印量适中，允许批次差异，选定。

## 已冻结接口

- 底盘主板 180 × 140 × 4 mm，目标整机不超过约 220 × 180 × 360 mm。
- TT 电机采用 70 × 23 × 25 mm 保守包络，卡箍座不依赖壳体螺孔。
- SG90 格式采用 23 × 12.2 × 29 mm；PAN、TILT、MOUTH 必须为可定位舵机。
- ESP32主控兼容区 66 × 32 mm，电子层使用双向长圆孔。
- 电池托盘兼容区 100 × 60 mm，使用绑带，保持低位安装。
- OLED 窗口兼容区 66 × 44 mm；HC-SR04 鼻部兼容区 48 × 23 mm；雷达胸口兼容区 45 × 35 mm。
- 黄色前后壳厚 1.4 mm，仅为非承力蒙皮；混元牛头通过头部接口板连接。

## 依据与不确定性

- Espressif 提供 DevKitC-1 官方尺寸图，但物料表照片看起来可能是另一种核心板，所以只将官方板作为较大参考：[Espressif ESP32-S3-DevKitC-1](https://docs.espressif.com/projects/esp-dev-kits/en/latest/esp32s3/esp32-s3-devkitc-1/user_guide_v1.0.html)。
- TowerPro 给出 SG90 本体 23 × 12.2 × 29 mm：[TowerPro SG90](https://towerpro.com.tw/product/sg90-7/)。
- 通用 TT 电机存在减速比、轴心和电机罐尺寸差异；DFRobot公开产品可用于电气与轴径风险参考，但不能证明主办方型号一致：[DFRobot TT Motor](https://www.dfrobot.com/product-100.html/)。
- Waveshare 2.42寸 OLED 参考模块为 61.5 × 39.5 mm：[Waveshare 2.42inch OLED](https://www.waveshare.com/wiki/2.42inch_OLED_Module)。
- HC-SR04 参考尺寸为 45 × 20 × 15 mm：[HC-SR04 Datasheet](https://www.digikey.in/en/htmldatasheets/production/1979760/0/0/1/hc-sr04)。

## 仍需主办方确认

- 51号 TT 电机是否配轮、轮径、减速比和堵转电流。
- 是否提供万向轮；若没有，使用打印后滑块。
- 46号 ESP32-S3 的具体板型和USB口方向。
- 60/61号雷达实际型号、接口和尺寸。
- 66号电源的电池化学体系、保护和最大放电能力。
- 50号 SG90 是否只有360°版本；若是，头部必须自备180°定位舵机。

## 验证门禁

数字阶段要求：所有打印件适配打印空间、装配包络合格、六组关键硬件无碰撞。实物阶段必须先打印电机座、电池托盘、电子层板和后滑块试片；未复测真实轮轴高度、电源能力和舵机限位前，不将 v0.2 标记为整套打印冻结版。

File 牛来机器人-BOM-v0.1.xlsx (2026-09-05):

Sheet: 牛来BOM
牛来机器人 BOM · v0.1
黑客松P0移动原型清单。比赛物料的“待购数量”表示尚未领取/获取；自备与升级件表示待采购。预算单价由团队拿到实物规格或真实报价后填写，空白不计入总额。雷达、电机、驱动、电池和舵机在门禁验证前不得宣称最终冻结。
序号 | 优先级 | 子系统 | 物料/部件 | 规格/用途 | 需求数量 | 已领/已有 | 待购数量 | 单位 | 来源 | 比赛编号 | 原图库存 | 选型状态 | 预算单价（元） | 预算小计（元） | 验证门禁 | 备注 | 来源证据
1 | P0 | 主控 | ESP32-S3 核心板 N16R8 | 16MB Flash + 8MB PSRAM；到手后复核板载模组与引脚 | 1 | 0 | 1 | 块 | 比赛物料 | 46 | 40 | 冻结 |  |  | G0：拍照记录丝印、供电方式、USB与可用GPIO | 核心计算与控制板 | 黑客松物料表-原图.png；系统架构 §5.1
2 | P0 | 移动底盘 | TT 马达 | 普通直流减速电机；仅作P0原型候选 | 2 | 0 | 2 | 个 | 比赛物料 | 51 | 20 | 原型候选 |  |  | G1：测额定电压、空载/堵转电流、假负载扭矩与温升 | 最终重量不足则换25GA/37GB；Sim2Real需编码器 | 黑客松物料表-原图.png；系统架构 §5.1
3 | P0 | 显示 | 2.42寸 OLED 屏幕 | 双眼共用一块屏；驱动芯片与I2C/SPI接口待确认 | 1 | 0 | 1 | 块 | 比赛物料 | 53 | 5 | 首选待实测 |  |  | G0：确认驱动芯片、电压、接口、刷新率和可视区域 | 数量有限，优先领取 | 黑客松物料表-原图.png；系统架构 §5.1
4 | P0 | 音频输出 | 4Ω喇叭 | 与MAX98357A I2S功放配套；额定功率待确认 | 1 | 0 | 1 | 个 | 比赛物料 | 55 | 30 | 待实测 |  |  | G0/G1：确认额定功率；最大音量无破音且不触发棕断 | ESP32不可直接驱动 | 黑客松物料表-原图.png；系统架构 §5.1
5 | P1 | 灯效 | WS2812灯带 | 状态与情绪灯效；控制线串阻并按长度核算供电 | 1 | 0 | 1 | 条 | 比赛物料 | 57 | 40 | P1可选 |  |  | G1：全亮峰值电流与音频/电机并发测试 | P0可先不装 | 黑客松物料表-原图.png；系统架构 §5.1
6 | P0 | 人员存在检测 | 24GHz毫米波雷达（120×120） | 原图描述：运动11m、微动10m；优先候选 | 1 | 0 | 1 | 块 | 比赛物料 | 61 | 5 | 首选待实测 |  |  | G0：确认型号、UART/GPIO、电压、FOV与静止人体检测 | 胸前非金属雷达窗后安装 | 黑客松物料表-原图.png；系统架构 §5.1
7 | P0 | 人员存在检测 | 24GHz毫米波雷达（100°） | 原图描述：16m存在、25m运动；61号不可用时备选 | 0 | 0 | 0 | 块 | 比赛物料 | 60 | 3 | 备选 |  |  | G0：仅在61号不可领或接口不兼容时评估 | 不与61号同时装机 | 黑客松物料表-原图.png；系统架构 §5.1
8 | P0 | 前向避障 | 超声波 HC-SR04 | 前方障碍检测；Echo必须做5V→3.3V电平转换 | 1 | 0 | 1 | 块 | 比赛物料 | 67 | 10 | 冻结 |  |  | G1：测盲区、壳体开孔影响与最大速度下停车距离 | 不能作为人员存在检测 | 黑客松物料表-原图.png；系统架构 §5.1
9 | P0 | 电源 | MP1584EN降压模块 | 逻辑/音频、舵机、电机分路候选；具体路数按实测调整 | 3 | 0 | 3 | 块 | 比赛物料 | 40 | 33 | 首选待实测 |  |  | G1：逐路测持续/峰值电流、纹波、温升与棕断 | 共地但负载分域；禁止从ESP32板给电机供电 | 黑客松物料表-原图.png；系统架构 §5.1
10 | P1 | 日志存储 | SD卡读卡模块 | P1结构化事件日志；P0先用串口/RAM环形日志 | 1 | 0 | 1 | 块 | 比赛物料 | 41 | 33 | P1可选 |  |  | G2：连续写入、掉电恢复与写满轮转测试 | 不默认存原始音频或图像 | 黑客松物料表-原图.png；系统架构 §5.1
11 | P0 | 原型调试 | 电阻包 | 超声波分压、上拉/下拉、LED与信号调试 | 1 | 0 | 1 | 包 | 比赛物料 | 47 | 30 | 冻结 |  |  | G0：确认常用阻值覆盖 | 最终装机改为焊接/端子连接 | 黑客松物料表-原图.png
12 | P0 | 原型调试 | 面包板 | 桌面联调使用，不进入移动整机 | 1 | 0 | 1 | 块 | 比赛物料 | 48 | 40 | 冻结 |  |  | G0：桌面原型可用；G2前移除 | 运动环境禁止把面包板当永久连接 | 黑客松物料表-原图.png
13 | P0 | 原型调试 | 杜邦线（公公/公母/母母） | 桌面联调线材 | 1 | 0 | 1 | 套 | 比赛物料 | 49 | 40 | 冻结 |  |  | G0：确认线序；G2前替换为锁止接插件 | 移动整机不依赖松动杜邦线 | 黑客松物料表-原图.png
14 | P0 | 本地输入 | 按键开关模块 | 鼻部确认/录音触发或调试输入；不承担急停 | 2 | 0 | 2 | 块 | 比赛物料 | 29 | 33 | 原型候选 |  |  | G0：去抖、长按与断线默认态测试 | 急停必须使用独立锁存式实体按钮 | 黑客松物料表-原图.png
15 | 升级 | 姿态感知 | 高性能6轴MEMS运动跟踪模块 | Sim2Real/姿态事件候选；确切芯片与量程未知 | 1 | 0 | 1 | 块 | 比赛物料 | 69（原图疑似59） | 5 | 待实测 |  |  | G0：核对原图误号、芯片、I2C地址、量程与采样率 | 原图编号顺序为58、69、60，保留疑点不擅自改号 | 黑客松物料表-原图.png
16 | P0 | 电机驱动 | DRV8833双路电机驱动模块 | 1.5A RMS/桥为芯片级参考；模块散热与堵转电流必须实测 | 1 | 0 | 1 | 块 | 自备 | — |  | 首选待实测 |  |  | G1：驱动持续/峰值电流、堵转保护与30分钟温升 | 若不满足则换更高电流驱动；TB6612仅备选 | 系统架构 §5.1
17 | P0 | 音频输入 | INMP441 I2S麦克风 | 16kHz单声道；耳部安装并远离扬声器和电机 | 1 | 0 | 1 | 块 | 自备 | — |  | 冻结 |  |  | G1：装壳前后KWS/录音信噪比与电机噪声测试 | 普通声音传感器不能替代 | 系统架构 §5.1
18 | P0 | 音频输出 | MAX98357A I2S功放 | 驱动4Ω扬声器；逻辑/音频独立供电 | 1 | 0 | 1 | 块 | 自备 | — |  | 冻结 |  |  | G1：最大音量、失真、温升与电源压降测试 | 与麦克风物理隔离 | 系统架构 §5.1
19 | P0 | 头部动作 | 180°可定位金属齿舵机 | 转头/点头两轴；扭矩按头部实重与力臂×2.5动态系数选 | 2 | 0 | 2 | 个 | 自备 | — |  | 待称重选型 |  |  | G0/G2：称重算扭矩、软/机械限位、卡滞与100次循环 | 禁止使用50号360°连续旋转舵机 | 系统架构 §5.1
20 | P0 | 嘴部动作 | 180°微型定位舵机 | 嘴部开合；弹簧回位并设置机械限位 | 1 | 0 | 1 | 个 | 自备 | — |  | 待称重选型 |  |  | G2：软限位、堵转超时、线缆余量和100次循环 | 可从轻载微型舵机起步 | 系统架构 §5.1
21 | P0 | 电源 | 2S带保护电池包 | 7.4V标称；容量、放电倍率、接口与认证待最终负载确认 | 1 | 0 | 1 | 包 | 自备 | — |  | 待实测 |  |  | G1：BMS、反接、峰值电流、低电阈值、固定与运输检查 | 不采用裸电芯或未知保护电池盒 | 系统架构 §5.1
22 | P0 | 充电 | 8.4V合规充电器 | 与2S电池化学体系、接口和充电电流匹配 | 1 | 0 | 1 | 个 | 自备 | — |  | 待实测 |  |  | G1：充电截止、温升、接口防呆；比赛版不边充边跑 | 必须与最终电池成套确认 | 系统架构 §5.1
23 | P0 | 安全 | 锁存式实体急停按钮 | 直接切断执行器电源；逻辑保持上电记录原因 | 1 | 0 | 1 | 个 | 自备 | — |  | 冻结 |  |  | G1：运动中触发/复位各50次，目标≤100ms进入安全态 | 普通按键模块不能替代 | 系统架构 §5.1
24 | P0 | 安全 | 保险丝及保险座 | 额定值按最终堵转与线路电流确定 | 1 | 0 | 1 | 套 | 自备 | — |  | 待实测 |  |  | G1：短时堵转与过流验证；不超过线材/接插件额定值 | 安装在电池总输出近端 | 系统架构 §5.1
25 | P0 | 电源 | 主电源开关 | 整机总电源；额定电流与电池输出匹配 | 1 | 0 | 1 | 个 | 自备 | — |  | 待实测 |  |  | G1：带载通断、温升、误触与维护可达性 | 与急停职责分开 | 系统架构 §5.1
26 | P0 | 移动底盘 | TT马达配套车轮 | 建议约65mm；最终轮径需与扭矩和壳体离地间隙联调 | 2 | 0 | 2 | 个 | 自备 | — |  | 原型候选 |  |  | G1：同轴度、打滑、急停、转弯和壳体干涉 | 轮径改变需同步修正控制参数 | 系统架构 §5.1
27 | P0 | 移动底盘 | 后部滚珠轮/万向轮 | 与两驱轮组成稳定三点支撑 | 1 | 0 | 1 | 个 | 自备 | — |  | 冻结 |  |  | G1：接缝通过、转向阻力、防卡滞与急停稳定性 | 优先低矮轻量结构 | 系统架构 §5.1
28 | P0 | 机械安全 | 前防倾支点 | 正常行驶不拖地，急停或前倾时先于外壳触地 | 1 | 0 | 1 | 个 | 3D打印 | — |  | 冻结 |  |  | G1/G3：最终重量假负载急停与转向各20次不倾倒 | 与底盘工程骨架一体设计 | 系统架构 §5.1
29 | P0 | 线束 | 锁止接插件与多规格线材套件 | JST-XH/端子等；按电流分线径并做应力释放 | 1 | 0 | 1 | 套 | 自备 | — |  | 待实测 |  |  | G2：摇晃、装拆、拉力、反接防呆与温升检查 | 杜邦线仅限桌面调试 | 系统架构 §5.1
30 | P0 | 机械装配 | M2/M3螺丝、螺母与垫片 | 覆盖舵机、主控、骨架、检修门和电池仓 | 1 | 0 | 1 | 套 | 自备 | — |  | 冻结 |  |  | G0：按实物孔位建立紧固件清单；完成3次无损装拆 | 不把关键承力件永久胶粘 | 系统架构 §5.1
31 | P0 | 机械装配 | M2/M3热熔螺母 | 打印件反复装拆接口 | 1 | 0 | 1 | 套 | 自备 | — |  | 冻结 |  |  | G0/G2：先打印孔径试片，再冻结热熔孔参数 | 按材料收缩修正孔径 | 系统架构 §5.1
32 | P0 | 3D打印 | PLA/PETG打印耗材 | 外观件优先PLA；电机座/舵机座等承力件优先PETG | 1 | 0 | 1 | 套 | 自备 | — |  | 冻结 |  |  | G0：切片包络、关键接口试片、层间强度与温升检查 | 混元/群核只负责外观；FreeCAD骨架负责承力孔位 | 系统架构 §5.1
33 | P1 | 扩展结构 | Insta360预留安装座 | 仅做加强区、螺纹/绑带接口和重心预留，不安装摄像机 | 1 | 0 | 1 | 个 | 3D打印 | — |  | P1可选 |  |  | G2：CAD干涉、检修门可达性与重心检查 | P0不采集图像 | 系统架构 §5.1
34 | 升级 | Sim2Real | 带编码器减速电机或编码器套件 | 替换/改造普通TT马达，提供真实轮速反馈 | 2 | 0 | 2 | 个 | 未来升级 | — |  | 升级项 |  |  | 升级门：编码器分辨率、轮速闭环、丢脉冲和低速控制验证 | 不与普通TT马达重复采购；二选一 | ESP32 Sim2Real调研；系统架构 §5.1
35 | 排除 | 舵机 | SG90（360°） | 连续旋转舵机，不能提供可重复的目标角度 | 0 | 0 | 0 | 个 | 比赛物料 | 50 | 30 | 排除 |  |  | 不得用于转头、点头或嘴部定位 | 可留作尾巴连续旋转实验，但不进入P0 BOM | 黑客松物料表-原图.png
36 | 排除 | 音频输入 | 麦克风声音传感器模块 | 只能检测声音幅度，不能替代语音采集麦克风 | 0 | 0 | 0 | 块 | 比赛物料 | 35 | 33 | 排除 |  |  | 不得用于ASR/KWS音频输入 | 语音链路使用INMP441 | 黑客松物料表-原图.png
37 | 排除 | 电源 | UNO R3移动电源电池盒+电池 | 保护、串数、容量、放电能力和接口均未确认 | 0 | 0 | 0 | 套 | 比赛物料 | 66 | 10 | 排除 |  |  | 未完成电池/BMS/充电合规核验前不得装机 | 正式方案使用成套2S保护电池与充电器 | 黑客松物料表-原图.png

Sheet: 比赛物料映射
比赛物料映射与旧编号纠错
只收录与牛来直接相关或曾被旧PRD误映射的条目。名称、编号和库存按原图抄录；原图本身存在“58、69、60”的编号跳号，因此六轴MEMS模块保留原图编号并标注疑点。库存是表中总数量，不代表团队已领取。
原图编号 | 原图名称 | 原图数量 | 牛来决策 | 计划数量 | 用途 | 纠错/限制 | 证据
29 | 按键开关模块 | 33 | 采用 | 2 | 鼻部确认/录音触发与调试输入 | 不能替代锁存急停 | 黑客松物料表-原图.png
35 | 麦克风声音传感器模块 | 33 | 排除 | 0 | 仅能做声音幅度检测 | 旧PRD将其当麦克风不准确；ASR使用INMP441 | 黑客松物料表-原图.png
40 | MP1584EN降压模块 | 33 | 采用 | 3 | 逻辑/音频、舵机、电机分路候选 | 具体路数和能力必须按峰值电流实测 | 黑客松物料表-原图.png
41 | SD卡读卡模块 | 33 | 采用 | 1 | P1结构化日志 | P0可先用串口/RAM环形日志 | 黑客松物料表-原图.png
46 | ESP32 S3核心板板载1-N16R8 | 40 | 采用 | 1 | 主控 | 旧PRD主控编号46正确；仍需复核实物丝印 | 黑客松物料表-原图.png
47 | 电阻包 | 30 | 采用 | 1 | 分压、上拉/下拉与调试 | 最终装机使用焊接/端子 | 黑客松物料表-原图.png
48 | 面包板 | 40 | 采用 | 1 | 桌面原型 | 不进入移动整机 | 黑客松物料表-原图.png
49 | 杜邦线（公公、公母、母母） | 40 | 采用 | 1 | 桌面联调 | G2前换锁止接插件 | 黑客松物料表-原图.png
50 | SG90（360） | 30 | 排除 | 0 | 连续旋转 | 旧PRD把50号用于转头/点头错误；需自备180°定位舵机 | 黑客松物料表-原图.png
51 | TT马达 | 20 | 采用 | 2 | P0两驱底盘 | 原型候选；最终按假负载和堵转电流决定 | 黑客松物料表-原图.png
52 | 1.54寸OLED屏幕 | 5 | 备选 | 0 | 小屏备选 | 首选53号2.42寸双眼共屏 | 黑客松物料表-原图.png
53 | 2.42寸OLED屏幕 | 5 | 采用 | 1 | 双眼表情显示 | 旧PRD写53/54不准确；54号是压力传感器 | 黑客松物料表-原图.png
54 | RFP602压力传感器 | 30 | 排除 | 0 | 本版无刚需 | 旧PRD将54号误当OLED；原图54号为压力传感器 | 黑客松物料表-原图.png
55 | 4欧喇叭 | 30 | 采用 | 1 | 语音播放 | 必须配MAX98357A功放 | 黑客松物料表-原图.png
57 | WS2812灯带 | 40 | 采用 | 1 | P1情绪灯效 | 先核算全亮电流 | 黑客松物料表-原图.png
69（疑似59） | （BCG）高性能6轴MEMS运动跟踪传感器模块 | 5 | 待确认 | 1 | 姿态/Sim2Real候选 | 原图顺序58、69、60，疑似编号笔误；先按原图保留 | 黑客松物料表-原图.png
60 | 24Ghz毫米波雷达（100度范围，16m存在，25m运动） | 3 | 备选 | 0 | 人员存在检测备选 | 61号不可用时再评估 | 黑客松物料表-原图.png
61 | 24Ghz毫米波雷达（120×120，运动11m，微动10m） | 5 | 采用 | 1 | 人员存在检测首选 | 型号、接口和参数均需实物核验 | 黑客松物料表-原图.png
66 | UNO R3移动电源电池盒+电池 | 10 | 排除 | 0 | 不进入正式供电 | 保护、放电与充电方案不明；改用成套2S保护电池 | 黑客松物料表-原图.png
67 | 超声波HC-SR04 | 10 | 采用 | 1 | 前向避障 | Echo必须做5V→3.3V电平转换 | 黑客松物料表-原图.png

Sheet: 采购缺口
采购缺口 · 自备 / 3D打印 / Sim2Real升级
本表由“牛来BOM”公式引用生成，请在主表更新数量、预算与状态。普通TT马达可支持P0开环原型，但Sim2Real需要编码器反馈；升级件不得与普通TT方案重复采购。
序号 | 缺口类型 | 子系统 | 物料 | 规格 | 需求数量 | 已领/已有 | 待购数量 | 单位 | 状态 | 预算单价（元） | 预算小计（元） | 验证门禁
16 | 自备 | 电机驱动 | DRV8833双路电机驱动模块 | 1.5A RMS/桥为芯片级参考；模块散热与堵转电流必须实测 | 1 | 0 | 1 | 块 | 首选待实测 |  |  | G1：驱动持续/峰值电流、堵转保护与30分钟温升
17 | 自备 | 音频输入 | INMP441 I2S麦克风 | 16kHz单声道；耳部安装并远离扬声器和电机 | 1 | 0 | 1 | 块 | 冻结 |  |  | G1：装壳前后KWS/录音信噪比与电机噪声测试
18 | 自备 | 音频输出 | MAX98357A I2S功放 | 驱动4Ω扬声器；逻辑/音频独立供电 | 1 | 0 | 1 | 块 | 冻结 |  |  | G1：最大音量、失真、温升与电源压降测试
19 | 自备 | 头部动作 | 180°可定位金属齿舵机 | 转头/点头两轴；扭矩按头部实重与力臂×2.5动态系数选 | 2 | 0 | 2 | 个 | 待称重选型 |  |  | G0/G2：称重算扭矩、软/机械限位、卡滞与100次循环
20 | 自备 | 嘴部动作 | 180°微型定位舵机 | 嘴部开合；弹簧回位并设置机械限位 | 1 | 0 | 1 | 个 | 待称重选型 |  |  | G2：软限位、堵转超时、线缆余量和100次循环
21 | 自备 | 电源 | 2S带保护电池包 | 7.4V标称；容量、放电倍率、接口与认证待最终负载确认 | 1 | 0 | 1 | 包 | 待实测 |  |  | G1：BMS、反接、峰值电流、低电阈值、固定与运输检查
22 | 自备 | 充电 | 8.4V合规充电器 | 与2S电池化学体系、接口和充电电流匹配 | 1 | 0 | 1 | 个 | 待实测 |  |  | G1：充电截止、温升、接口防呆；比赛版不边充边跑
23 | 自备 | 安全 | 锁存式实体急停按钮 | 直接切断执行器电源；逻辑保持上电记录原因 | 1 | 0 | 1 | 个 | 冻结 |  |  | G1：运动中触发/复位各50次，目标≤100ms进入安全态
24 | 自备 | 安全 | 保险丝及保险座 | 额定值按最终堵转与线路电流确定 | 1 | 0 | 1 | 套 | 待实测 |  |  | G1：短时堵转与过流验证；不超过线材/接插件额定值
25 | 自备 | 电源 | 主电源开关 | 整机总电源；额定电流与电池输出匹配 | 1 | 0 | 1 | 个 | 待实测 |  |  | G1：带载通断、温升、误触与维护可达性
26 | 自备 | 移动底盘 | TT马达配套车轮 | 建议约65mm；最终轮径需与扭矩和壳体离地间隙联调 | 2 | 0 | 2 | 个 | 原型候选 |  |  | G1：同轴度、打滑、急停、转弯和壳体干涉
27 | 自备 | 移动底盘 | 后部滚珠轮/万向轮 | 与两驱轮组成稳定三点支撑 | 1 | 0 | 1 | 个 | 冻结 |  |  | G1：接缝通过、转向阻力、防卡滞与急停稳定性
28 | 3D打印 | 机械安全 | 前防倾支点 | 正常行驶不拖地，急停或前倾时先于外壳触地 | 1 | 0 | 1 | 个 | 冻结 |  |  | G1/G3：最终重量假负载急停与转向各20次不倾倒
29 | 自备 | 线束 | 锁止接插件与多规格线材套件 | JST-XH/端子等；按电流分线径并做应力释放 | 1 | 0 | 1 | 套 | 待实测 |  |  | G2：摇晃、装拆、拉力、反接防呆与温升检查
30 | 自备 | 机械装配 | M2/M3螺丝、螺母与垫片 | 覆盖舵机、主控、骨架、检修门和电池仓 | 1 | 0 | 1 | 套 | 冻结 |  |  | G0：按实物孔位建立紧固件清单；完成3次无损装拆
31 | 自备 | 机械装配 | M2/M3热熔螺母 | 打印件反复装拆接口 | 1 | 0 | 1 | 套 | 冻结 |  |  | G0/G2：先打印孔径试片，再冻结热熔孔参数
32 | 自备 | 3D打印 | PLA/PETG打印耗材 | 外观件优先PLA；电机座/舵机座等承力件优先PETG | 1 | 0 | 1 | 套 | 冻结 |  |  | G0：切片包络、关键接口试片、层间强度与温升检查
33 | 3D打印 | 扩展结构 | Insta360预留安装座 | 仅做加强区、螺纹/绑带接口和重心预留，不安装摄像机 | 1 | 0 | 1 | 个 | P1可选 |  |  | G2：CAD干涉、检修门可达性与重心检查
34 | 未来升级 | Sim2Real | 带编码器减速电机或编码器套件 | 替换/改造普通TT马达，提供真实轮速反馈 | 2 | 0 | 2 | 个 | 升级项 |  |  | 升级门：编码器分辨率、轮速闭环、丢脉冲和低速控制验证

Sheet: 状态汇总
BOM 状态汇总
所有指标均引用“牛来BOM”。预算只统计已填写单价且仍有待购数量的项目；当前空白预算不代表零成本。正式采购冻结必须完成G0实物确认和G1底盘/电源安全验证。
关键指标 | 结果 | 来源分类 | 条目数 | 优先级 | 条目数
BOM总条目 | 37 | 比赛物料 | 18 | P0 | 29
P0条目 | 29 | 自备 | 16 | P1 | 3
比赛物料条目 | 18 | 3D打印 | 2 | 升级 | 2
自备条目 | 16 | 未来升级 | 1 | 排除 | 3
待实测/待选型 | 13
排除项 | 3
当前预算总额（元） | ¥0.00
冻结前的四个动作
1. G0：逐件拍照并记录型号、接口、电压、尺寸；原图编号只作领取索引。
2. G1：用最终重量假负载测试TT马达、驱动、分路电源、急停、停止距离与温升。
3. 头部称重后按力臂×2.5动态系数选择180°定位舵机；50号360°舵机不得替代。
4. 若进入Sim2Real，再采购编码器或编码电机；策略只输出v/ω，安全层保留最终裁决。

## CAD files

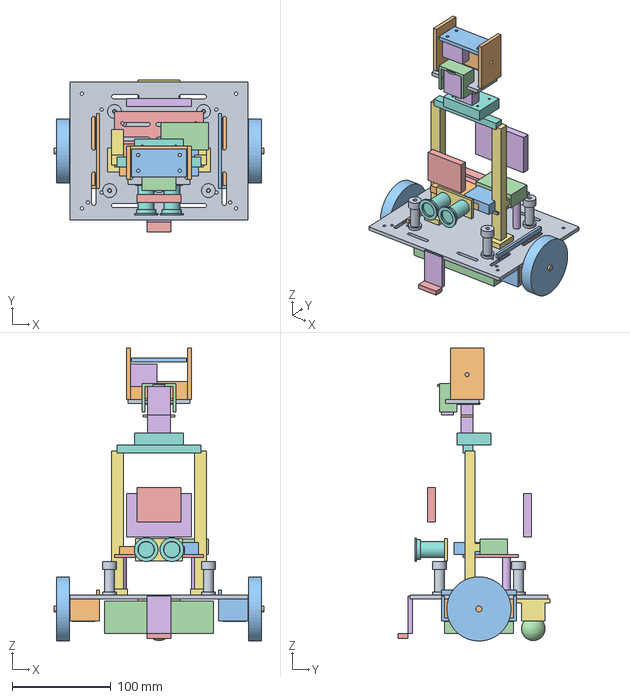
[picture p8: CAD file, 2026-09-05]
outputs/牛来机器人-A2L打印包-v0.5/05_工程源文件和报告/niulai-shell-interface-frame-assembly-v0.3.step
212.0 x 154.0 x 296.4 mm

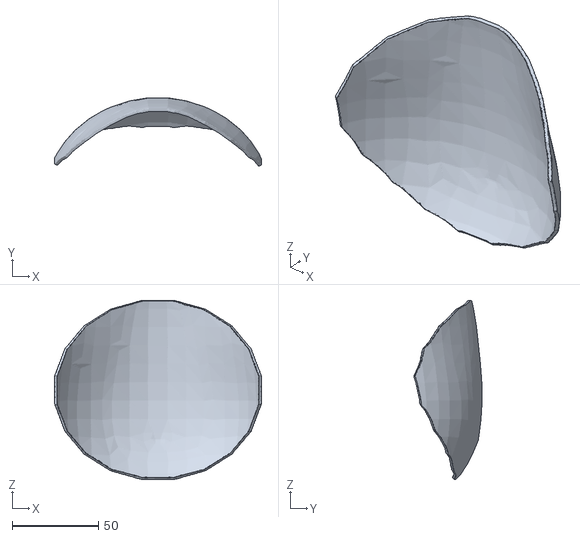
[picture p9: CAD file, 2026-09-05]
mechanical/v0.4/stl/06_body_rear_shell.stl
120.0 x 39.7 x 104.0

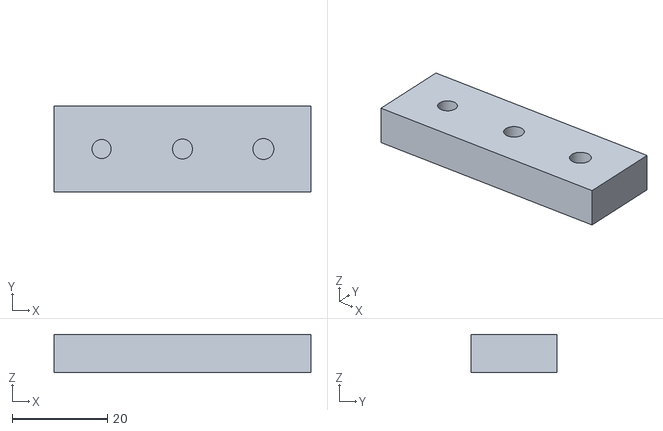
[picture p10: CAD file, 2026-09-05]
outputs/牛来-第一步只打印这一个-小白专用/只打印这个_19_m3_heatset_coupon.stl
54.0 x 18.0 x 8.00

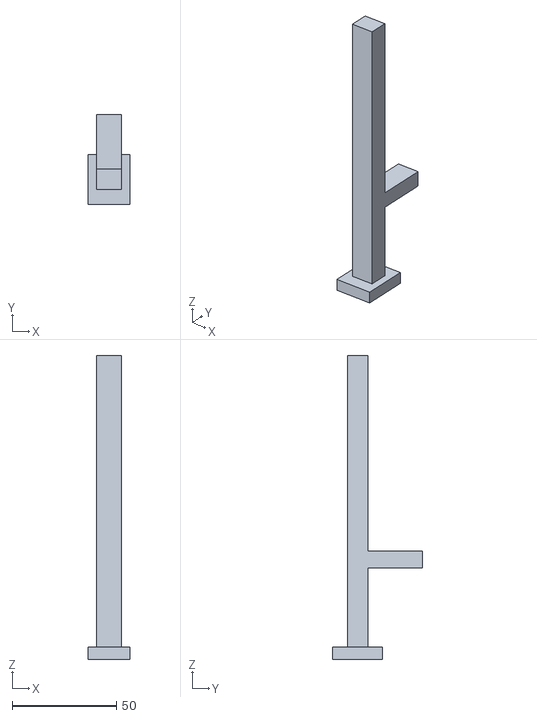
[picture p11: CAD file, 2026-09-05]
outputs/牛来机器人-A2L打印包-v0.5-小白版/02_结构件_确认孔径后打印/07_neck_column_left.stl
20.0 x 43.0 x 146.0

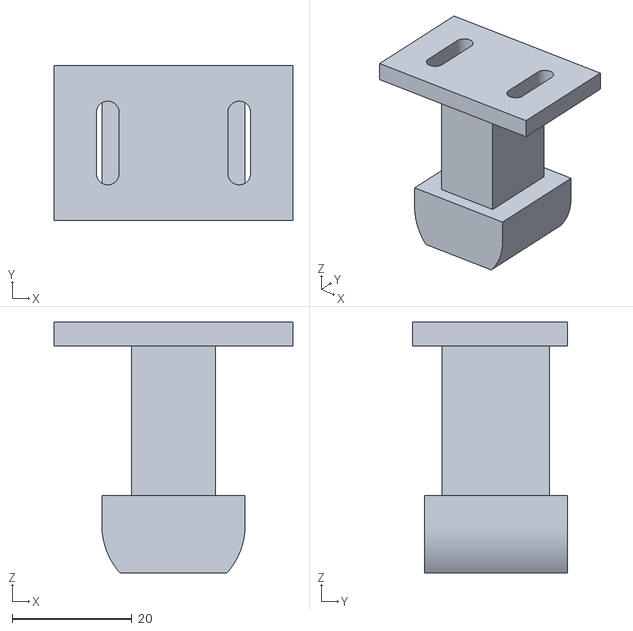
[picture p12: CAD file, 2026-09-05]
outputs/牛来机器人-A2L打印包-v0.5-小白版/03_可选件/18_rear_skid_fallback.stl
40.0 x 26.0 x 42.0

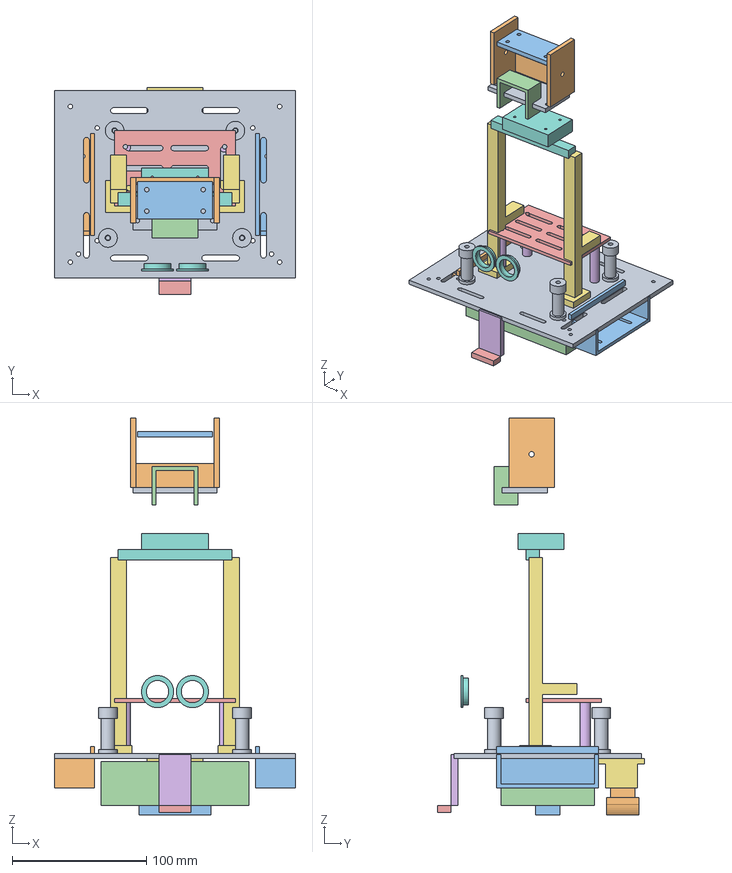
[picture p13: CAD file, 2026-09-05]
outputs/牛来机器人-A2L打印包-v0.5-小白版/05_工程源文件和报告/niulai-shell-interface-frame-print-parts-v0.3.step
180.0 x 154.0 x 296.0 mm

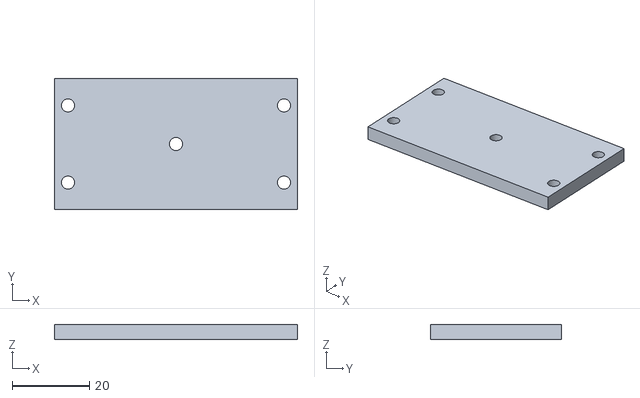
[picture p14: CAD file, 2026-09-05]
outputs/牛来机器人-A2L打印包-v0.5/02_结构件_确认孔径后打印/10_pan_platform.stl
63.0 x 34.0 x 4.00

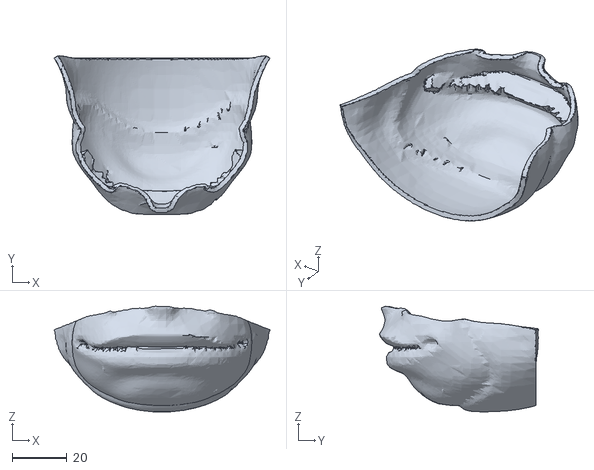
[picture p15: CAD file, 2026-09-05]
outputs/牛来机器人-A2L打印包-v0.5/04_外壳_最后打印/09_mouth_shell.stl
79.1 x 58.2 x 38.7

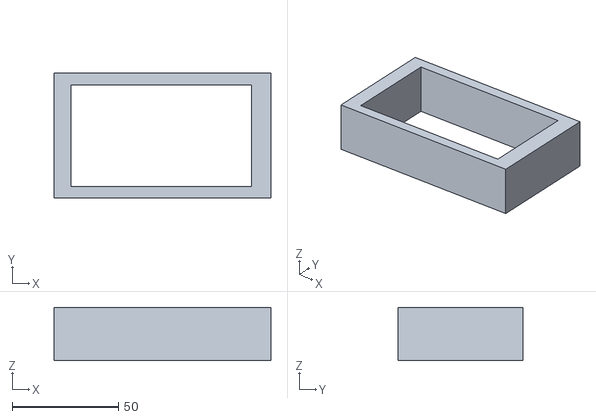
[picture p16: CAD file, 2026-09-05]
solidwork/kaifban.STL
102.1 x 58.9 x 25.0

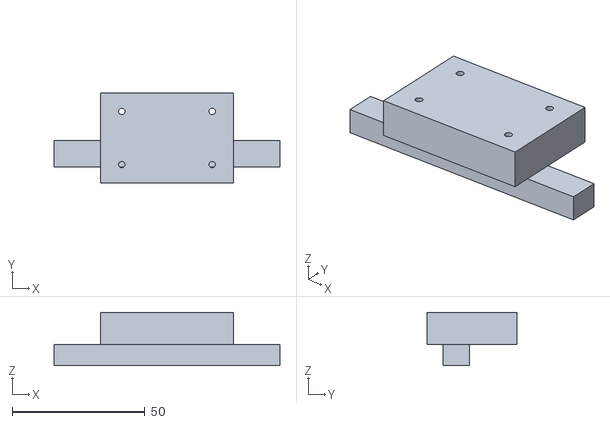
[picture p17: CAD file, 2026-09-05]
outputs/牛来机器人-A2L打印包-v0.5-小白版/02_结构件_确认孔径后打印/09_neck_crossbeam.stl
85.0 x 34.0 x 20.0

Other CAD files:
mechanical/v0.1/niulai-open-frame-assembly-v0.1.step
mechanical/v0.1/niulai-open-frame-print-parts-v0.1.step
mechanical/v0.1/niulai-open-frame-v0.1.FCStd
mechanical/v0.1/preview_meshes/01_PrintedParts.stl
mechanical/v0.1/preview_meshes/02_HardwarePlaceholders.stl
mechanical/v0.1/preview_meshes/03_ReservedInterfaces.stl
mechanical/v0.1/preview_meshes/04_ChassisBase.stl
mechanical/v0.1/preview_meshes/05_MotorMountLeft.stl
mechanical/v0.1/preview_meshes/06_MotorMountRight.stl
mechanical/v0.1/preview_meshes/07_BatteryTray.stl
mechanical/v0.1/preview_meshes/08_ElectronicsDeck.stl
mechanical/v0.1/preview_meshes/09_StandoffSet.stl
mechanical/v0.1/preview_meshes/10_NeckColumnLeft.stl
mechanical/v0.1/preview_meshes/11_NeckColumnRight.stl
mechanical/v0.1/preview_meshes/12_NeckCrossbeam.stl
mechanical/v0.1/preview_meshes/13_PanPlatform.stl
mechanical/v0.1/preview_meshes/14_TiltBracket.stl
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

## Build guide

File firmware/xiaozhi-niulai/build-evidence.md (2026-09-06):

# IDF BUILD_PASS / FLASH_PASS — 实体对话基础连通通过

2026-09-06 11:22 完整构建成功，随后 COM6 以 460800 波特率仅更新 `0x20000` 应用分区，写入 2,805,264 字节并通过 esptool `Hash of data verified`。未重写 NVS 和资源分区。用户已确认台架接线准备。

- 当前应用 SHA256：`2FA63F2A6FF446D013F48B4BBF83476DF73034289DA482F9ED7A28F3EB279C46`。
- native `application.cc`：`20B99D565A9E04A5207163A648FBAD95B51CF0C98990BD41793EC9C69A303EF9`；`application.h` 沿用 `302D03C06EED68A3B4BE5BB0B7236CAAD53AD5E359830B6686B2B6E04AE2849B`。
- `generated_assets.bin`：3,127,685 字节，SHA256 `B1FBEF49B009A0B0A352BBFFF089DCBF1B53BDF7F7F075F669E4C077078DEC5C`，与前次烧录资源一致。
- 日志：`.scratch/codex-round4/idf-build.log`、`flash-write.log`、`serial-after.log`。旧应用回退副本 `application-before.bin` 留在同一忽略目录；当前镜像含私有设备配置，未复制到公开交付目录。
- 烧录后实际重启：ELF SHA 前缀 `c22101d8c`；启动 768 ms 加载 srmodels，778 ms 记录本地资源应用，7358 ms 初始化 `detector: MultiNet`。未再出现引擎拒绝替换模型的旧故障。板子取得 IP `192.168.18.251`。
- 持久源码检查 `check_application_intro.py` 与 `check_application_voice_startup.py` 均通过。11:31 用户确认“对话通了”；串口记录 BOOT 后实体转录与回答，以及一次实际关键词 `niulai` 检测 → 妈妈 → 收音 → 回答。可靠性分母和延迟门禁仍未完成，详见 `docs/codex-dialogue-2026-09-06.md`。
- 当前已验基础连通镜像私有副本：`.scratch/codex-round4/working-dialogue.bin`，SHA256 与本段当前应用一致。串口观察已结束并释放 COM6，未重置设备。

## 历史构建：10:33（第二轮，彼时未烧录）

2026-09-06 10:33 +08，第二轮完整构建成功，exit 0。妈妈等待改为可取消定时事件，包含旧回复过滤和正常 VAD 回复保护，已通过独立源码复核及实际 C++ 检查。

- `xiaozhi.bin`：2,804,672 字节，SHA256 `F1275BF9EA427DDE4C7F28AC77BF304102949FE070CB22A83C52C8AB3F5A900D`。
- `merged-binary.bin`：11,516,293 字节，SHA256 `117443B1EC9B94455C56D0CC0E07C55ECB29010C2CD52D0F31B20907B39CA0D9`。
- 应用副本：`outputs/niulai-codex-round2-2026-09-06/xiaozhi.bin`；日志：`.scratch/codex-round2/idf-build.log`；完整记录：`.grok-loop/evidence/runs/20260906-codex-round2.json`。
- 命令：`python scripts/build.py niulai-s3-expand-v17 --name niulai-s3-expand-v17`。IDF export 将工具入口解析到 `E:\AI_TOY_NATIVE\esp-idf-v6.0.2`；UTF-8 环境已设置。
- native `application.cc` SHA256 `458AE720797A69152B115FB09D0DBFC7CA3932911FAF7C070C74763197CC37A2`，`application.h` SHA256 `302D03C06EED68A3B4BE5BB0B7236CAAD53AD5E359830B6686B2B6E04AE2849B`。
- 仍未烧录、未打开串口、未做实体声音与动作验收；仅更改固件目标 IP 不代表服务已可从板端访问。

## 历史构建：10:02（第一轮接管）

2026-09-06 10:02 +08，Codex 接管修复构建成功，exit 0。命令仍为 `python scripts/build.py niulai-s3-expand-v17 --name niulai-s3-expand-v17`，另设 `PYTHONUTF8=1`、`PYTHONIOENCODING=utf-8`。

- `xiaozhi.bin`：2,803,312 字节，SHA256 `E8259C5CC48CDBDF40F6CDD600D3C70B46C6CDD8D8CFBC68B57453240D7B3C22`。
- `merged-binary.bin`：11,516,293 字节，SHA256 `15DF8DBA2C49E749DFC9082803BBCA13B87B711FA38276D74D5D9D059630C002`。
- overlay/native 的 `niulai_life.cc`、`niulai_life.h`、`niulai_presence.h` 已同步；本次包含测距失效 UNKNOWN 保护。
- 应用固件副本：`outputs/niulai-codex-2026-09-06/xiaozhi.bin`；日志：`.scratch/codex-takeover/idf-build-utf8.log`（均相对项目根目录）。
- COM6 只验证到 CH340 枚举；未烧录、未听到真机声音、未测停止时延。合并镜像不能当成保留 NVS 的更新包。

## 历史构建：09:25（修复前）

Date: 2026-09-06 09:25 +08  
Command: `python scripts/build.py niulai-s3-expand-v17`  
Cwd: `E:\XIAOZHI_NATIVE\xiaozhi-esp32`  
IDF: 6.0.2  
Exit: 0  
Heard / COM6: NOT_RUN

| artifact | size | sha256 | mtime |
|---|---:|---|---|
| `build/xiaozhi.bin` | 2803120 (0x2ac5b0) | `60387221D40C45855BFBAB35B992AE2E538B64397BE0A5F6E8D75E95EEA4CDC0` | 2026-09-06 09:25:09 |
| `build/merged-binary.bin` | 11516293 (0xafb985) | `1CC75308E710C7B5188A6098AE212D46D0AD95A18CE34B42EC2428AECFBFEAEB` | 2026-09-06 09:25:15 |

Overlay `niulai_life.cc` sha256[:12] `AE5245A671E7` **MATCH** native `main/boards/niulai-s3-expand-v17/niulai_life.cc`.

This is source+build identity, not axis calibration and not on-device playback.

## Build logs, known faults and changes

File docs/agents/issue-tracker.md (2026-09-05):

# Issue tracker: GitHub

Issues and PRDs for this repo live as GitHub issues on **23xxCh/ox-robot**.
Use the `gh` CLI for all operations. Pass `-R 23xxCh/ox-robot` unless you are
already inside a clone whose `origin` is that repo.

## Conventions

- **Create an issue**: `gh issue create -R 23xxCh/ox-robot --title "..." --body "..."`. Use a heredoc for multi-line bodies.
- **Read an issue**: `gh issue view <number> -R 23xxCh/ox-robot --comments`, filtering comments by `jq` and also fetching labels.
- **List issues**: `gh issue list -R 23xxCh/ox-robot --state open --json number,title,body,labels,comments --jq '[.[] | {number, title, body, labels: [.labels[].name], comments: [.comments[].body]}]'` with appropriate `--label` and `--state` filters.
- **Comment on an issue**: `gh issue comment <number> -R 23xxCh/ox-robot --body "..."`
- **Apply / remove labels**: `gh issue edit <number> -R 23xxCh/ox-robot --add-label "..."` / `--remove-label "..."`
- **Close**: `gh issue close <number> -R 23xxCh/ox-robot --comment "..."`

This workspace is not yet a git clone of `ox-robot`. Until `origin` points at that repo, always pass `-R 23xxCh/ox-robot`. After the first push, `gh` can infer the repo from `git remote -v`.

## When a skill says "publish to the issue tracker"

Create a GitHub issue on `23xxCh/ox-robot`.

## When a skill says "fetch the relevant ticket"

Run `gh issue view <number> -R 23xxCh/ox-robot --comments`.

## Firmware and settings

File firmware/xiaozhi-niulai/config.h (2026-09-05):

#ifndef _BOARD_CONFIG_H_
#define _BOARD_CONFIG_H_

#include <driver/gpio.h>

#define AUDIO_INPUT_SAMPLE_RATE  16000
#define AUDIO_OUTPUT_SAMPLE_RATE 24000

// 如果使用 Duplex I2S 模式，请注释下面一行
#define AUDIO_I2S_METHOD_SIMPLEX

#ifdef AUDIO_I2S_METHOD_SIMPLEX

#define AUDIO_I2S_MIC_GPIO_WS   GPIO_NUM_4
#define AUDIO_I2S_MIC_GPIO_SCK  GPIO_NUM_5
#define AUDIO_I2S_MIC_GPIO_DIN  GPIO_NUM_6
#define AUDIO_I2S_SPK_GPIO_DOUT GPIO_NUM_7
#define AUDIO_I2S_SPK_GPIO_BCLK GPIO_NUM_15
#define AUDIO_I2S_SPK_GPIO_LRCK GPIO_NUM_16

#else

#define AUDIO_I2S_GPIO_WS GPIO_NUM_4
#define AUDIO_I2S_GPIO_BCLK GPIO_NUM_5
#define AUDIO_I2S_GPIO_DIN  GPIO_NUM_6
#define AUDIO_I2S_GPIO_DOUT GPIO_NUM_7

#endif


// KY-016 S (3-pin module = one PWM channel, typically red).
// GPIO 21 is LCD SCL; GPIO 12 is TP4054 CHRG. Rear-left servo is GPIO 9.
#define BUILTIN_LED_GPIO        GPIO_NUM_14
#define BOOT_BUTTON_GPIO        GPIO_NUM_0
// KY-004: idle HIGH, pressed LOW. GPIO 47 is LCD MOSI — do not use it.
#define KEY_BUTTON_GPIO         GPIO_NUM_18
#define TOUCH_BUTTON_GPIO       GPIO_NUM_NC
#define VOLUME_UP_BUTTON_GPIO   GPIO_NUM_NC
#define VOLUME_DOWN_BUTTON_GPIO GPIO_NUM_NC

#define ULTRASONIC_TRIG_GPIO    GPIO_NUM_8
#define ULTRASONIC_ECHO_GPIO    GPIO_NUM_17
#define SERVO_FL_GPIO           GPIO_NUM_10
#define SERVO_FR_GPIO           GPIO_NUM_11
// GPIO 12 is TP4054 CHRG + charge LED on 小智 S3 扩展板 V1.7. PWM fights that net.
#define SERVO_RL_GPIO           GPIO_NUM_9
#define SERVO_RR_GPIO           GPIO_NUM_13


#define DISPLAY_BACKLIGHT_PIN GPIO_NUM_42
#define DISPLAY_MOSI_PIN      GPIO_NUM_47
#define DISPLAY_CLK_PIN       GPIO_NUM_21
#define DISPLAY_DC_PIN        GPIO_NUM_40
#define DISPLAY_RST_PIN       GPIO_NUM_45
#define DISPLAY_CS_PIN        GPIO_NUM_41


#ifdef CONFIG_LCD_ST7789_240X320
#define LCD_TYPE_ST7789_SERIAL
#define DISPLAY_WIDTH   240
#define DISPLAY_HEIGHT  320
#define DISPLAY_MIRROR_X false
#define DISPLAY_MIRROR_Y false
#define DISPLAY_SWAP_XY false
#define DISPLAY_INVERT_COLOR    true
#define DISPLAY_RGB_ORDER  LCD_RGB_ELEMENT_ORDER_RGB
#define DISPLAY_OFFSET_X  0
#define DISPLAY_OFFSET_Y  0
#define DISPLAY_BACKLIGHT_OUTPUT_INVERT false
#define DISPLAY_SPI_MODE 0
#endif

#ifdef CONFIG_LCD_ST7789_240X320_NO_IPS
#define LCD_TYPE_ST7789_SERIAL
#define DISPLAY_WIDTH   240
#define DISPLAY_HEIGHT  320
#define DISPLAY_MIRROR_X false
#define DISPLAY_MIRROR_Y false
#define DISPLAY_SWAP_XY false
#define DISPLAY_INVERT_COLOR    false
#define DISPLAY_RGB_ORDER  LCD_RGB_ELEMENT_ORDER_RGB
#define DISPLAY_OFFSET_X  0
#define DISPLAY_OFFSET_Y  0
#define DISPLAY_BACKLIGHT_OUTPUT_INVERT false
#define DISPLAY_SPI_MODE 0
#endif

#ifdef CONFIG_LCD_ST7789_170X320
#define LCD_TYPE_ST7789_SERIAL
#define DISPLAY_WIDTH   170
#define DISPLAY_HEIGHT  320
#define DISPLAY_MIRROR_X false
#define DISPLAY_MIRROR_Y false
#define DISPLAY_SWAP_XY false
#define DISPLAY_INVERT_COLOR    true
#define DISPLAY_RGB_ORDER  LCD_RGB_ELEMENT_ORDER_RGB
#define DISPLAY_OFFSET_X  35
#define DISPLAY_OFFSET_Y  0
#define DISPLAY_BACKLIGHT_OUTPUT_INVERT false
#define DISPLAY_SPI_MODE 0
#endif

#ifdef CONFIG_LCD_ST7789_172X320
#define LCD_TYPE_ST7789_SERIAL
#define DISPLAY_WIDTH   172
#define DISPLAY_HEIGHT  320
#define DISPLAY_MIRROR_X false
#define DISPLAY_MIRROR_Y false
#define DISPLAY_SWAP_XY false
#define DISPLAY_INVERT_COLOR    true
#define DISPLAY_RGB_ORDER  LCD_RGB_ELEMENT_ORDER_RGB
#define DISPLAY_OFFSET_X  34
#define DISPLAY_OFFSET_Y  0
#define DISPLAY_BACKLIGHT_OUTPUT_INVERT false
#define DISPLAY_SPI_MODE 0
#endif

#ifdef CONFIG_LCD_ST7789_240X280
#define LCD_TYPE_ST7789_SERIAL
#define DISPLAY_WIDTH   240
#define DISPLAY_HEIGHT  280
#define DISPLAY_MIRROR_X false
#define DISPLAY_MIRROR_Y false
#define DISPLAY_SWAP_XY false
#define DISPLAY_INVERT_COLOR    true
#define DISPLAY_RGB_ORDER  LCD_RGB_ELEMENT_ORDER_RGB
#define DISPLAY_OFFSET_X  0
#define DISPLAY_OFFSET_Y  20
#define DISPLAY_BACKLIGHT_OUTPUT_INVERT false
#define DISPLAY_SPI_MODE 0
#endif

#ifdef CONFIG_LCD_ST7789_240X240
#define LCD_TYPE_ST7789_SERIAL
#define DISPLAY_WIDTH   240
#define DISPLAY_HEIGHT  240
#define DISPLAY_MIRROR_X false
#define DISPLAY_MIRROR_Y false
#define DISPLAY_SWAP_XY false
#define DISPLAY_INVERT_COLOR    true
#define DISPLAY_RGB_ORDER  LCD_RGB_ELEMENT_ORDER_RGB
#define DISPLAY_OFFSET_X  0
#define DISPLAY_OFFSET_Y  0
#define DISPLAY_BACKLIGHT_OUTPUT_INVERT false
#define DISPLAY_SPI_MODE 0
#endif

#ifdef CONFIG_LCD_ST7789_240X240_7PIN
#define LCD_TYPE_ST7789_SERIAL
#define DISPLAY_WIDTH   240
#define DISPLAY_HEIGHT  240
#define DISPLAY_MIRROR_X false
#define DISPLAY_MIRROR_Y false
#define DISPLAY_SWAP_XY false
#define DISPLAY_INVERT_COLOR    true
#define DISPLAY_RGB_ORDER  LCD_RGB_ELEMENT_ORDER_RGB
#define DISPLAY_OFFSET_X  0
#define DISPLAY_OFFSET_Y  0
#define DISPLAY_BACKLIGHT_OUTPUT_INVERT false
#define DISPLAY_SPI_MODE 3
#endif
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

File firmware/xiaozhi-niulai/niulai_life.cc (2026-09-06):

#include "niulai_life.h"

#include "application.h"
#include "board.h"
#include "config.h"
#include "niulai_face_display.h"

#include <driver/gpio.h>
#include <esp_log.h>
#include <esp_random.h>
#include <esp_rom_sys.h>
#include <esp_timer.h>

#include <cstring>
#include <string>

#define TAG "NiulaiLife"

namespace {
constexpr int64_t kBrainRetryUs = 18LL * 1000 * 1000;
constexpr uint32_t kEchoTimeoutUs = 25000;
constexpr uint32_t kCenterUs = 1500;
constexpr uint32_t kMaxDuty = (1u << 14) - 1;
}  // namespace

void NiulaiLife::Start(Display* display) {
    display_ = display;
    gpio_config_t trig = {};
    trig.pin_bit_mask = 1ULL << ULTRASONIC_TRIG_GPIO;
    trig.mode = GPIO_MODE_OUTPUT;
    gpio_config(&trig);
    gpio_set_level(ULTRASONIC_TRIG_GPIO, 0);

    gpio_config_t echo = {};
    echo.pin_bit_mask = 1ULL << ULTRASONIC_ECHO_GPIO;
    echo.mode = GPIO_MODE_INPUT;
    echo.pull_down_en = GPIO_PULLDOWN_ENABLE;
    gpio_config(&echo);

    xTaskCreatePinnedToCore(TaskTrampoline, "niulai_life", 4096, this, 5, nullptr, 0);
    ESP_LOGI(TAG, "life loop started TRIG=%d ECHO=%d", (int)ULTRASONIC_TRIG_GPIO,
             (int)ULTRASONIC_ECHO_GPIO);
}

void NiulaiLife::TaskTrampoline(void* arg) {
    static_cast<NiulaiLife*>(arg)->Loop();
}

void NiulaiLife::Loop() {
    while (true) {
        float cm = ReadCm();
        int64_t now = esp_timer_get_time();
        bool close = NiulaiDistanceValid(cm) && cm < 55.0f;
        last_close_ = close;
        Presence next = ObserveNiulaiDistance(cm, now, far_since_us_, presence_);

        if (next != presence_) {
            OnPresence(next);
        }

        if (close || next == Presence::Unknown) {
            ParkLegs();
        } else if (now < motion_until_us_) {
            SecretWalk();
        } else {
            directed_ = false;
            if (presence_ == Presence::Present) {
                HoldCenter();
            } else if (presence_ == Presence::Absent) {
                SecretWalk();
                if (now - last_brain_us_ >= kBrainRetryUs) {
                    last_brain_us_ = now;
                    secret_retry_++;
                    // ABSENT-only quiet window: wiggle, no WSS / local ogg.
                    // Asked PRESENT walks are not banned here (PulseMotion when not close).
                    if (secret_retry_ % 3 == 0) {
                        ESP_LOGI(TAG, "secret quiet window");
                    } else {
                        AskBrainSecret();
                    }
                }
            }
        }

        if (++log_tick_ % 10 == 0) {
            ESP_LOGI(TAG, "cm=%.1f presence=%d", cm, (int)presence_.load());
        }

        vTaskDelay(pdMS_TO_TICKS(200));
    }
}

float NiulaiLife::ReadCm() {
    gpio_set_level(ULTRASONIC_TRIG_GPIO, 0);
    esp_rom_delay_us(3);
    gpio_set_level(ULTRASONIC_TRIG_GPIO, 1);
    esp_rom_delay_us(10);
    gpio_set_level(ULTRASONIC_TRIG_GPIO, 0);

    int64_t wait_start = esp_timer_get_time();
    while (gpio_get_level(ULTRASONIC_ECHO_GPIO) == 0) {
        if (esp_timer_get_time() - wait_start > kEchoTimeoutUs) {
            return -1.0f;
        }
    }
    int64_t rise = esp_timer_get_time();
    while (gpio_get_level(ULTRASONIC_ECHO_GPIO) == 1) {
        if (esp_timer_get_time() - rise > kEchoTimeoutUs) {
            return -1.0f;
        }
    }
    int64_t width = esp_timer_get_time() - rise;
    return (static_cast<float>(width) * 0.0343f) / 2.0f;
}

void NiulaiLife::WritePulseUs(int index, uint32_t pulse_us) {
    if (pulse_us < 1100) {
        pulse_us = 1100;
    }
    if (pulse_us > 1900) {
        pulse_us = 1900;
    }
    uint32_t duty = pulse_us * kMaxDuty / 20000u;
    ledc_set_duty(LEDC_LOW_SPEED_MODE, channels_[index], duty);
    ledc_update_duty(LEDC_LOW_SPEED_MODE, channels_[index]);
}

void NiulaiLife::HoldCenter() {
    for (int i = 0; i < 4; ++i) {
        WritePulseUs(i, kCenterUs);
    }
}

void NiulaiLife::ParkLegs() {
    motion_until_us_ = 0;
    directed_ = false;
    HoldCenter();
}

void NiulaiLife::PulseMotion(const char* dir, int ms) {
    if (presence_ == Presence::Unknown || last_close_) {
        ParkLegs();
        return;
    }
    if (ms < 0) {
        ms = 0;
    }
    if (ms > 2000) {
        ms = 2000;
    }
    if (dir != nullptr && strcmp(dir, "stop") == 0) {
        ParkLegs();
        return;
    }
    if (dir != nullptr && (strcmp(dir, "left") == 0 || strcmp(dir, "right") == 0)) {
        gait_ = 3;
    } else if (dir != nullptr && strcmp(dir, "back") == 0) {
        gait_ = 1;
    } else {
        gait_ = 0;
    }
    directed_ = true;
    wiggle_phase_ = 1;
    motion_until_us_ = esp_timer_get_time() + static_cast<int64_t>(ms) * 1000;
}

void NiulaiLife::SnapFreeze() {
    ParkLegs();
    PostFace("neutral", "");
}

void NiulaiLife::SecretWalk() {
    // Random gait, short burst then park so 360° servos stop.
    // Lua niu.walk/turn keeps the gait PulseMotion already chose.
    if (!directed_ && wiggle_phase_ == 0) {
        gait_ = static_cast<int>(esp_random() % 4);
    }
    wiggle_phase_ = (wiggle_phase_ + 1) % 14;
    if (wiggle_phase_ >= 4) {
        HoldCenter();
        return;
    }
    int sign = (wiggle_phase_ < 2) ? 1 : -1;
    int amp = 160 + static_cast<int>(esp_random() % 120);
    switch (gait_) {
        case 1:  // front pair
            WritePulseUs(0, kCenterUs + sign * amp);
            WritePulseUs(1, kCenterUs - sign * amp);
            WritePulseUs(2, kCenterUs);
            WritePulseUs(3, kCenterUs);
            break;
        case 2:  // rear pair
            WritePulseUs(0, kCenterUs);
            WritePulseUs(1, kCenterUs);
            WritePulseUs(2, kCenterUs - sign * amp);
            WritePulseUs(3, kCenterUs + sign * amp);
            break;
        case 3:  // turn in place
            WritePulseUs(0, kCenterUs + sign * amp);
            WritePulseUs(1, kCenterUs + sign * amp);
            WritePulseUs(2, kCenterUs + sign * amp);
            WritePulseUs(3, kCenterUs + sign * amp);
            break;
        default:  // diagonal
            WritePulseUs(0, kCenterUs + sign * amp);
            WritePulseUs(1, kCenterUs - sign * amp);
            WritePulseUs(2, kCenterUs - sign * amp);
            WritePulseUs(3, kCenterUs + sign * amp);
            break;
    }
}
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

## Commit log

2026-09-05 Initial import of 牛来 / ox-robot.
    Include the local brain, architecture docs, Arduino bring-up firmware, and mechanical STLs. Ignore the Xiaozhi tutorial dump, WeChat export, Blender files over GitHub's 100MB limit, and packed print 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
    [01_PrintedParts.stl, 01_chassis_base.stl, 02_AlternativeParts.stl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]
2026-09-05 Add Checkpoint 1 firmware overlay, local brain lifecycle, and progress note.
    Ship the niulai-s3-expand-v17 board overlay with local mama PCM, FastAPI lifecycle/memory/IM rehearsal, and the 9.5 checkpoint writeup for ox-robot.
    [kaifban.STL]
2026-09-05 Add 牛来机器人 Checkpoint 1 progress report and servo midpoint hold.
    Name the official progress note after the product, and park SG90s at 1.5 ms so 360-degree servos stop spinning.
2026-09-05 Add the GitHub README for 牛来 / ox-robot.
    Describe the single-board architecture, pin map, firmware flash, and local brain so judges can open the repo cold.
2026-09-05 Remove stray dumps and session clutter from the workspace.
    Drop the Xiaozhi tutorial bundle, WeChat export helper, UUID BOM scratch, and a misplaced HCSR04 JSON file so the repo root is only 牛来 project files.
    [牛来机器人-BOM-v0.1.xlsx]
2026-09-05 Add board-local presence loop and noon Submission pack.
    Ultrasonic PRESENT freezes servos; 8s without near echoes allows a small SECRET wiggle. Mama stays local. Submission markdown covers Part 5 integrity and the 90-second demo.
2026-09-05 Make SECRET walk interruptible and pack Checkpoint 2.
    Near-range ultrasonic now parks all four legs at 1500 us on the first ping. After 8 s without a close reading the board runs a diagonal wiggle, hard-capped at 1100-1900 us, and snaps back the moment a hand returns. Checkpoint 2, Submission, and the 90-second cue card are in the repo; Feishu has the same notes.
    [niulai_life.cc]
2026-09-05 Park SECRET wiggle at 1500 us and document the COM6 reflash.
    360-degree servos spin if held off-center, so SECRET now twitches 400 ms then sits at midpoint for about 2 s. Mama, BOOT, and the key park legs immediately. README, Checkpoint 2, Submission, and the Feishu paste block match the 18:24 COM6 image.
    [niulai_life.cc, niulai_s3_expand_v17.cc]
2026-09-05 Move rear-left servo off GPIO 12 onto GPIO 9.
    GPIO 12 is the V1.7 charger-status net, so PWM there fights CHRG and the other three legs. SECRET still parks at 1500 us. Brain can speak Opus to a stock Xiaozhi socket; this board still stays local 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
2026-09-05 Document GPIO 9 rear-left servo and the 18:42 COM6 image.
    GPIO 12 is the V1.7 charger LED, so leftover 10/11/12/13 notes would send a yellow wire onto CHRG. Checkpoint 2, Submission, README, and the Feishu paste block now match the flashed pin map.
2026-09-05 Play local personality lines and randomize SECRET motion.
    When nobody is near, the board mutters canned complaints and switches gaits. When a hand appears it parks the legs and says a greeting. Speaker volume is forced to 90 so 妈妈 is no longer silent text.
    [niulai_life.cc, niulai_s3_expand_v17.cc]
2026-09-05 Encode local voice lines as Ogg Opus.
    PlaySound drops Vorbis pages, which is why the screen showed 妈妈 with a silent speaker. mama/hi/secret clips are now 48 kHz Opus like the stock chimes.
2026-09-05 Document local SECRET voice clips and the 19:06 COM6 image.
    Mama, the near-range greeting, and three SECRET lines are board-local Opus, not Xiaozhi cloud. Checkpoint 2, Submission, README, and the Feishu paste block now match the randomized gait and 90 volume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
2026-09-05 Add the public 牛来 /life page with red-green tests.
    GET /life is a static product page: freeze, greeting, GPIO 9, GitHub, no official cloud. Rehearsal stays at /. Site tests start red on 404 and go green with the route.
2026-09-05 Let the /life page write 牛来's backstory and talk through an LLM.
    Presence splits alone-mutter versus in-front speech. Tests stay offline; a live Zhipu key is used only outside pytest. The board still plays local Opus until it is pointed at this brain.
2026-09-05 Keep /life on the laptop and the 90-second demo on the board.
    The public /life page can write backstory through DashScope Qwen. Freeze, mama, and SECRET mutters stay board-local C and local Opus. README, Checkpoint 2, Submission, and the Feishu paste block say 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
2026-09-05 Cut SECRET audio the moment a hand returns.
    PlaySound queued Opus frames behind the SECRET mutter, so freeze parked the legs while the speaker kept talking. Mama, the key, and the near-range greeting now ResetDecoder first. COM6 has the 19:57 image.
    [niulai_life.cc, niulai_s3_expand_v17.cc]
2026-09-05 Let SECRET talk to the laptop brain, with a local clip fallback.
    Presence frames go to private ws://192.168.18.242:8000/xiaozhi/v1/ only. Xiaozhi cloud URLs are refused. If that socket is down the board still parks, says 妈妈 on approach, and plays secret1.ogg. Free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
2026-09-05 牛来人格提示词
2026-09-05 Align demo docs and brain to locked polite-chat product.
    PRESENT near freezes and aborts roast; wake/BOOT/KY-004 start polite listen-think-speak on the private brain. Wake word is single niu lai. ABSENT mutters about every 11s. Duplicate ABSENT no longer double-speaks.
    [niulai_life.cc, niulai_s3_expand_v17.cc, test_lifecycle.py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]
2026-09-05 Freeze wins over Lua walk while a person is present.
    PRESENT near no longer sends niulai motion; ABSENT can still pulse-walk with ttl<=2000. Overlay life loop matches native freeze-first order.
    [niulai_life.cc, niulai_s3_expand_v17.cc, test_protocol.py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]
2026-09-05 Keep mama-then-polite, and allow asked-for PRESENT walks.
    Approach still freezes legs. PRESENT chat may send niu.walk/turn
    with ttl<=2000. Docs match the movie-clip-then-listen demo.
2026-09-05 Wire MemoryStore into the private WSS speak path.
    Wake bumps mama count. Approach/abort stores the interrupted line.
    ABSENT mutters can roast that and skip the last five lines.
    [test_memory.py, test_protocol.py]
2026-09-05 Mark P0-8 pytest green after memory wiring.
2026-09-06 Consume an interrupt once, and keep the loop files.
2026-09-06 人格提示词牛来无人个版
2026-09-06 Accept ClawBot events without walking while frozen.
2026-09-06 Consume interrupts on ABSENT speak, and hash firmware in /health.
2026-09-06 fix(loop-1.0): stabilize device dialogue and authentication
    Sync the verified firmware and backend snapshot with source checks and
    recorded dialogue evidence. Keep active local development out of this
    commit. Offline regression: 181 passed, 1 warning; package HTTP checks: 3/3.
2026-09-06 docs(loop-1.0): add final report and README architecture
    Add the five-page Niulai final report in PDF and Word, the system diagram,
    and the runnable backend package with verification records. Physical video
    is prepared by the project owner; task reliability and stop latency remain
    pending structured acceptance.
    [测试记录.csv]
